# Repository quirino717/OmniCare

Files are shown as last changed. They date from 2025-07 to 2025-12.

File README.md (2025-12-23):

# OmniCare — Robô Móvel Omnidirecional para Navegação Multi-Andares

> Repositório do Trabalho de Conclusão de Curso de Engenharia de Robôs - OmniCare




<p align="center">
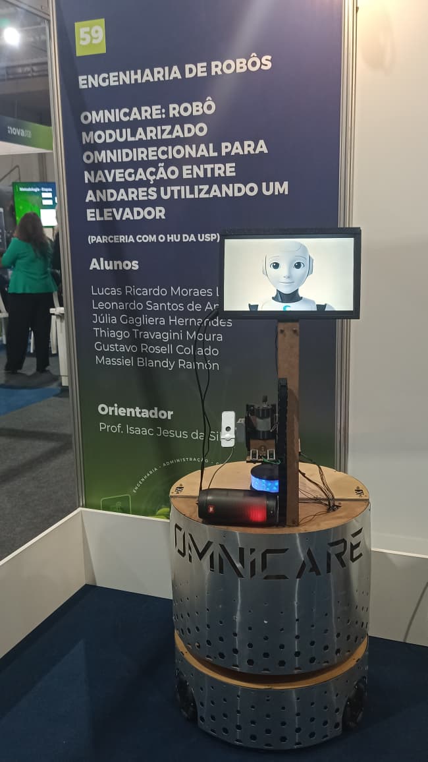
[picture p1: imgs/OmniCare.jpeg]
OmniCare
  
</p>

---

## 📚 Sumário
- [Visão Geral](#visão-geral)
- [Estrutura do Projeto](#instalação-e-build)
- [Como executar o robô de forma teleoperada](#como-executar-o-robô-de-forma-teleoperada)
- [Como executar o robô para mapear (SLAM ToolBox)](#como-executar-o-robô-para-mapear)
- [Como executar a stack do NAV2](#como-executar-a-stack-do-nav2)

- [Documentações](#documentações)
- [Autores](#👤-autores)
- [Licença](#📝-licença)

---
## Visão Geral

O **OmniCare** é um robô móvel omnidirecional desenvolvido para navegação autônoma em ambientes complexos, com capacidade de deslocamento entre **múltiplos andares** utilizando **elevadores reais**.  
O projeto envolve integração profunda de **ROS 2**, **STM32**, **percepção computacional**, **planejamento de movimento**, **manipulação**, além de uma arquitetura de software robusta baseada em máquina de estados.

## Estrutura do Projeto
 
```bash
.
├── firmware/ # Se concentra todos os firmwares utilizados 
├── hardware/ # Documentação e arquivos da parte eletrônica
├── mechanics/ # Arquivos CAD e modelagem mecânica
├── scripts/
│   ├── record_navigation.sh # Script para gravar a bag de navegação
│   ├── record_vision.sh # Script para gravar a bag de visão
│   ├── scripts.sh # Script para setup do robô
│   ├── setup.sh # Script para setup do robô
│   ├── startup.sh # Script que é rodado quando a jetson "boota"
│   └── sync_omnicare.sh # Script para rsync nootebook --> jetson
│
├── software/src/ # ROS 2 workspace
│   ├── omnicare_bringup/ # Launch principal do OmniCare
│   ├── omnicare_control/ # Controle de movimento do robô
│   ├── omnicare_description/ # Descrição do robô (URDF/XACRO)
│   ├── omnicare_msgs/ # Definição de mensagens customizadas
│   ├── omnicare_navigation/ # Configuração do SLAM e NAV2
│   ├── omnicare_simulation/ # Simulação no Gazebo
│   └── omnicare_vision/ # Módulo de visão computacional
│
└── README.md # Este documento
```

## Instalação e Build

```bash
git clone https://github.com/Thgm01/OmniCare.git
cd OmniCare/software/
rosdep install --from-paths . -y --ignore-src
colcon build --symlink-install
source install/setup.bash
```

## Como executar o robô de forma teleoperada
A teleoperação do OmniCare pode ser feita **diretamente na Jetson** (via SSH) ou **remotamente do seu computador**, desde que ambos utilizem o mesmo **ROS_DOMAIN_ID**.

### **1 - Acesse a Jetson via SSH**
```bash
ssh robot@robot.local
```

### **2 - Inicie o robô (bringup completo)**  
Este comando inicializa os drivers, sensores, TFs e toda a estrutura necessária para operar o robô no mundo real.

```bash
ros2 launch omnicare_bringup load_real_robot.launch.py
```

### **3 - Teleoperação usando teclado**

Você pode rodar o teleop **localmente no seu PC** ou **dentro da Jetson via SSH**.

1. Configure no seu PC o mesmo `ROS_DOMAIN_ID` usado pela Jetson:
```bash
export ROS_DOMAIN_ID=<mesmo_da_jetson>
```

2. Execute o teleop do seu computador:
```bash
ros2 run teleop_twist_keyboard teleop_twist_keyboard
```

## Como executar o robô para mapear
O mapeamento do OmniCare pode ser feita **diretamente na Jetson** (via SSH) ou **remotamente do seu computador**, desde que ambos utilizem o mesmo **ROS_DOMAIN_ID**.

### **1 - Acesse a Jetson via SSH**
```bash
ssh robot@robot.local
```

### **2 - Inicie o robô (bringup completo)**  
Este comando inicializa os drivers, sensores, TFs e toda a estrutura necessária para operar o robô no mundo real.

```bash
ros2 launch omnicare_bringup load_real_robot.launch.py
```

### **3 - Teleoperação usando teclado**

Você pode rodar o teleop **localmente no seu PC** ou **dentro da Jetson via SSH**.

1. Configure no seu PC o mesmo `ROS_DOMAIN_ID` usado pela Jetson:
```bash
export ROS_DOMAIN_ID=<mesmo_da_jetson>
```

2. Execute o teleop do seu computador:
```bash
ros2 run teleop_twist_keyboard teleop_twist_keyboard
```

### **4 - Mapeamento usando o SLAM ToolBox**

Você pode rodar **localmente no seu PC** ou **dentro da Jetson via SSH**.

1. Configure no seu PC o mesmo `ROS_DOMAIN_ID` usado pela Jetson:
```bash
export ROS_DOMAIN_ID=<mesmo_da_jetson>
```

2. Execute o teleop do seu computador:
```bash
ros2 launch navigation_pkg mapping_slam_toolbox.launch.py
```

3. Após rodar o launch do SLAM ToolBox, abra o RViz2 no seu computador com essa configuração
```bash
software/src/omnicare_navigation/navigation_pkg/config/rviz/mapping_cartographer.rviz
```

## Como executar a stack do NAV2
A navegação do OmniCare é preferivel ser feita **em um notebook externo** por conta do processamento, é necessário que ambos utilizem o mesmo **ROS_DOMAIN_ID**.

### **1 - Acesse a Jetson via SSH**
```bash
ssh robot@robot.local
```

### **2 - Inicie o robô (bringup completo)**  
Este comando inicializa os drivers, sensores, TFs e toda a estrutura necessária para operar o robô no mundo real.

```bash
ros2 launch omnicare_bringup load_real_robot.launch.py
```

### **3 - Navegando usando a stack do NAV2**

É recomendado rodar **localmente no seu PC** por conta do processamento pesado de CPU.

1. Configure no seu PC o mesmo `ROS_DOMAIN_ID` usado pela Jetson:
```bash
export ROS_DOMAIN_ID=<mesmo_da_jetson>
```

2. Execute o teleop do seu computador:
```bash
ros2 launch navigation_pkg navigation2.launch.py
```

3. Após rodar o launch do NAV2, abra o RViz2 no seu computador com essa configuração
```bash
software/src/omnicare_navigation/navigation_pkg/config/rviz/navigation.rviz
``` 
## Documentações

A documentação do OmniCare está organizada de forma modular, abrangendo mecânica, hardware, firmware e software.  
Cada módulo possui sua própria pasta dedicada, permitindo uma navegação clara e objetiva.

---

### Documentação Mecânica
A pasta [`mechanics/`](mechanics/) contém:

- Modelos CAD completos do robô  
- Estrutura da base omnidirecional  
- Projeto do manipulador linear  
- Especificações de motores, rodas e sensores mecânicos  

---

### Documentação Hardware
A pasta [`hardware/`](hardware/) contém:

- Esquemáticos elétricos  
- Layout da arquitetura eletrônica  
- Detalhamento dos módulos embarcados  

---

### Documentação Software (ROS 2)

O software do OmniCare é composto por múltiplos pacotes ROS 2, cada um contendo suas características e funcionalidades.

### Pacotes ROS 2
---

### 🔹 [omnicare_behavior](software/src/omnicare_behavior/)
O pacote **omnicare_behavior**, a máquina de estados responsável por coordenar toda a missão do robô. É ele quem controla o fluxo completo da navegação entre diferentes andares, integrando percepção, navegação, manipulação e troca de mapas. O Behavior Manager decide quando iniciar a navegação, alinhar ao elevador, interagir com o painel, trocar de mapa no momento correto e retomar o trajeto até o destino final.

---

### 🔹 [omnicare_bringup](software/src/omnicare_bringup/)
O pacote **omnicare_bringup** é responsável por inicializar todo o sistema do robô, tanto no ambiente real quanto no simulador. Ele carrega automaticamente os módulos essenciais, incluindo o ROS 2 Control, a comunicação com os microcontroladores (STM32), e os sensores embarcados, como o LiDAR. Em resumo, é o pacote que prepara todo o ecossistema do OmniCare para operação, garantindo que hardware, drivers e interfaces estejam corretamente configurados antes da execução dos módulos de navegação e comportamento.

---

### 🔹 [omnicare_control](software/src/omnicare_control/)
O **omnicare_control** é um conjunto de três pacotes que implementa toda a camada de controle de baixo nível do OmniCare. Ele integra a cinemática, a dinâmica e as interfaces de hardware do robô, permitindo que o sistema execute movimentos omnidirecionais de forma precisa e compatível com o ROS 2 Control e o movimento do manipulador.

---

### 🔹 [omnicare_description](software/src/omnicare_description/)

O **omnicare_description** é o pacote responsável por reunir toda a descrição física do OmniCare, incluindo o seu URDF completo, as malhas utilizadas para visualização e os plugins necessários para simulação e controle. Ele define a estrutura mecânica, sensores, atuadores e juntas do robô, garantindo que sua representação virtual seja fiel ao modelo real. Além disso, integra os plugins do Gazebo para simulação física e dos ROS 2 Control para conexão com controladores e interfaces de hardware, servindo como a base unificada para visualização, simulação e operação do robô tanto no ambiente virtual quanto no mundo real.

---

### 🔹 [omnicare_hri](software/src/omnicare_hri/)

O **omnicare_hri** engloba os pacotes dedicados à Interação Humano–Robô (HRI) no OmniCare. Ele é composto por um módulo responsável pelas animações faciais do robô — incluindo expressões exibidas na tela frontal, LEDs de sinalização e o buzzer — permitindo que o robô comunique estados e ações de forma mais amigável ao usuário. Complementando essa funcionalidade, o segundo pacote implementa uma interface para um controle remoto baseado em ESP32, possibilitando acionar comandos do robô de maneira simples.

---

### 🔹 [omnicare_msgs](software/src/omnicare_msgs/)

O **omnicare_msgs** é o pacote responsável por definir todas as mensagens customizadas utilizadas pelos diferentes módulos do OmniCare, incluindo topics, services e actions. Ele centraliza estruturas de dados específicas do projeto — como comandos de movimento, estados do comportamento, mensagens do manipulador, sinais de expressão e eventos da navegação multi-andares — garantindo comunicação padronizada e consistente entre os diversos nós do sistema.

---

### 🔹 [omnicare_navigation](software/src/omnicare_navigation/)
O **omnicare_navigation** reúne um conjunto de pacotes responsáveis por toda a camada de navegação do OmniCare. Ele inclui o pacote do LiDAR, que fornece os dados primários de percepção espacial, e o pacote da IMU, atualmente integrado ao sistema mas ainda não utilizado diretamente na navegação. O núcleo deste módulo é o navigation_pkg, que contém os launch files do NAV2, incluindo configuração de planejadores, BTs e parâmetros de navegação. Além disso, o conjunto oferece launchs específicos para mapeamento do ambiente, permitindo a criação e atualização de mapas utilizados pelo Nav2 e pelo AMCL.

---

### 🔹 [omnicare_simulation](software/src/omnicare_simulation/)
O **omnicare_simulation** reúne todos os recursos necessários para a simulação completa do OmniCare no Gazebo, incluindo launch files dedicados para iniciar o robô, seus sensores e o ambiente virtual. Além disso, o pacote implementa serviços auxiliares de teletransporte dentro do simulador para validação da navegação de multi-andares.

---

### 🔹 [omnicare_vision](software/src/omnicare_vision/)
O **omnicare_vision** concentra todos os pacotes relacionados ao sistema de visão do OmniCare. Ele inclui o usb_cam, que atua como driver da câmera e fornece o fluxo de imagens bruto; o floor_detector, responsável por realizar a inferência sobre o display do elevador e classificar corretamente o andar atual; e o dataset_generator, um pacote auxiliar utilizado para gerar datasets automaticamente a partir de rosbags.

## 👤 Autores

**Lucas Lagoeiro**  
Graduando em Engenharia de Robôs – Centro Universitário FEI  
Área: Programação e Elétrica   
[LinkedIn](https://www.linkedin.com/in/llagoeiro/) • [GitHub](https://github.com/LucasLagoeiro)

**Thiago Moura**  
Graduando em Engenharia de Automação e Controle – Centro Universitário FEI  
Área: Programação e Elétrica  
[LinkedIn](https://www.linkedin.com/in/thiago-t-moura/) • [GitHub](https://github.com/Thgm01)

**Massiel Blandy**  
Graduando em Engenharia de Automação e Controle – Centro Universitário FEI  
Área: Programação  
[LinkedIn](https://www.linkedin.com/in/massiel-blandy-ram%C3%B3n-65214829a/) • [GitHub](https://github.com/massiblandy)

**Júlia Hernandes**  
Graduanda em Engenharia Elétrica – Centro Universitário FEI  
Área: Elétrica  
[LinkedIn](https://www.linkedin.com/in/j%C3%BAlia-gagliera-hernandes-40545b221/) 

**Gustavo Rosell**  
Graduando em Engenharia de Automação e Controle – Centro Universitário FEI  
Área: Mecânica  
[LinkedIn](https://linkedin.com/in/gustavo-rosell) 

**Leonardo Quirino**  
Graduando em Engenharia de Robôs – Centro Universitário FEI  
Área: Mecânica  
[LinkedIn](https://www.linkedin.com/in/leonardo-quirino-353486218/)

## 📝 Licença

Este projeto está licenciado sob a Licença MIT.

Isso significa que você pode usar, copiar, modificar, mesclar, publicar, distribuir, sublicenciar e/ou vender cópias do software, desde que mantenha o aviso de copyright e a permissão de licença incluídos em todas as cópias ou partes substanciais do software.

Para mais detalhes, consulte o arquivo [LICENSE](LICENSE).

## 📝 TODO — Documentação dos Pacotes

A seguir está o checklist de pacotes do OmniCare que terão documentação detalhada seguindo o mesmo padrão adotado no `omnicare_behavior`.

### 📦 Pacotes ROS 2

- [x] **omnicare_behavior** — Behavior Manager (FSM, Action Server, multi-andares)
- [x] **omnicare_bringup** — Inicialização do robô (real e simulação)
- [ ] **omnicare_control**
  - [x] omnidrive_stm32
  - [ ] serial_interface_pkg
- [ ] **omnicare_description** — URDF, meshes e plugins
- [ ] **omnicare_hri**
  - [ ] omnicare_expression
- [ ] **omnicare_msgs** — Mensagens, serviços e actions customizadas
- [ ] **omnicare_navigation** — Nav2, LiDAR, IMU e mapeamento
  - [ ] navigation_pkg
- [ ] **omnicare_simulation** — Gazebo, launches e serviços de teleporte
- [ ] **omnicare_vision**
  - [ ] floor_detector
  - [ ] dataset_generator

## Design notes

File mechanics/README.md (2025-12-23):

# OmniCare Mechanics

O OmniCare foi projetado para operar em ambientes hospitalares, com ênfase em mobilidade omnidirecional, modularidade estrutural e compatibilidade com normas de circulação. 
A base possui arquitetura circular, construída com chapas de MDF e perfis de alumínio, permitindo a integração do sistema elétrico, do manipulador e de um compartimento de carga modular. 
O manipulador foi desenvolvido para interação com elevadores, contando com graus de liberdade translacionais e rotacional no efetuador final.

Nesta seção você encontrará todos os materiais relacionados ao desenvolvimento mecânico do robô, incluindo:

- Modelos CAD completos do robô;
- Estrutura da base omnidirecional;
- Projeto do manipulador;
- Especificações de motores e rodas.

Esses arquivos permitem entender a composição estrutural do robô, seus componentes principais e a lógica de montagem mecânica.
O acesso às modelagens e documentos está disponível no link abaixo:

Link para o Drive com os modelos CAD e arquivos mecânicos:
https://drive.google.com/drive/folders/1Ufkg-2wcXs-KffQ5NBY0fZA2kzGGDrn_?usp=drive_link

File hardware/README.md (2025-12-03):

# OmniCare Hardware

O hardware da OmniCare foi projetado para ser **modular, confiável e duradouro**.  
Neste diretório estão reunidos todos os arquivos relacionados ao desenvolvimento elétrico do projeto.  
A seguir, é apresentada a arquitetura geral que descreve como a parte elétrica foi concebida.

## Considerações

Todo o projeto elétrico foi desenvolvido utilizando o software **Altium Designer**, versão *24.8.2*  
(até o momento, ainda é possível utilizar o e-mail institucional da FEI para acesso).

Com exceção da *Driver Board*, todas as placas foram manufaturadas no **CLE da FEI**.  
As placas de duas faces foram projetadas para que os componentes sejam soldados apenas na face **Bottom**,  
utilizando *vias* para permitir a passagem de sinais entre as camadas. Essas vias foram planejadas de forma a permitir o uso de qualquer condutor simples (por exemplo: terminais de resistores ou fios finos).

Dentro de cada pasta estão incluídos:  
– **Arquivos de fabricação**, identificando o local de produção (CLE ou JLCPCB);  
– **PDF de documentação**;  
– **Arquivos do Altium** correspondentes ao projeto.

## Arquitetura Geral

## Placas Eletrônicas da OmniCare

### Power Board
Placa responsável por **receber a energia da bateria**, realizar a **regulação das tensões** utilizadas no robô e fazer a **distribuição segura** para todos os módulos.

### Driver Board
Placa destinada ao **acionamento dos motores**, contendo os circuitos de potência e controle necessários para operar as rodas omnidirecionais com precisão e confiabilidade.

### Base Board
Placa responsável por **interligar os módulos eletrônicos da base**, roteando sinais dos motores, encoders e sensores, além de fornecer **pontos de conexão e organização elétrica** entre os subsistemas.

### IHR Board (HRI Board)
Placa responsável pela **interação humano–robô**, integrando LEDs, botões e elementos visuais utilizados para comunicação e feedback ao usuário.

### Manip Board
Placa dedicada ao **controle do manipulador frontal**, gerenciando motores e sensores usados para acionar os botões do elevador de forma precisa.

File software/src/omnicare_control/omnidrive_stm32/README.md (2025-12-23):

# OmniDrive STM32 (`omnidrive_stm32`)

O **`omnidrive_stm32`** é o pacote responsável por implementar a **Hardware Interface** do **ROS 2 Control** para a base móvel do OmniCare, realizando a ponte entre os controladores de alto nível e o **microcontrolador STM32** que executa o controle de baixo nível dos motores.

Em outras palavras, este pacote “fecha” o conceito do `ros2_control`: enquanto os controladores (ex.: `omnidirectional_controllers`) calculam as velocidades desejadas, o `omnidrive_stm32` é o componente que **envia esses comandos ao STM32** e **lê o feedback** (encoders/estado) para disponibilizar ao restante do sistema.

---

## Considerações

O pacote foi desenvolvido para garantir:

- Integração nativa com o **`omnidirecional_controllers`** do ROS 2 Control;
- Comunicação robusta com o STM32 (ex.: serial/UART/USB, conforme configuração do projeto);
- Publicação de estados para depuração e monitoração;
- Separação clara entre **controle de alto nível (ROS 2)** e **controle de baixo nível (STM32)**.

---

## Diagrama de Fluxo

<p align="center">
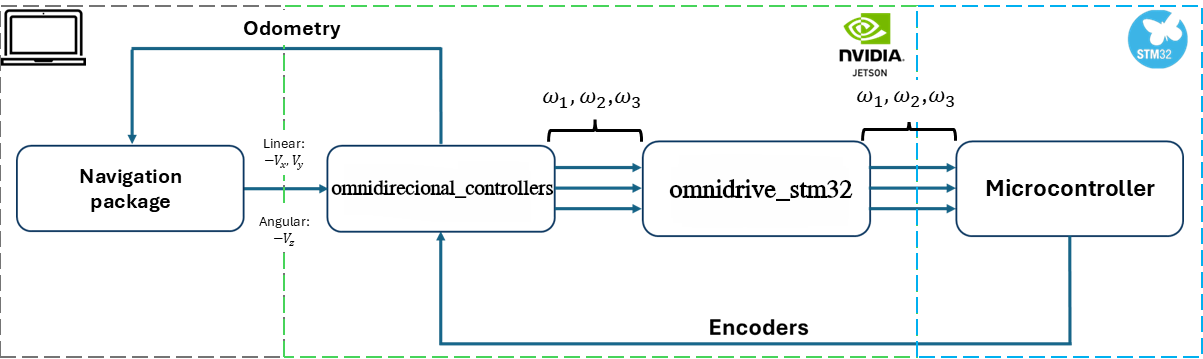
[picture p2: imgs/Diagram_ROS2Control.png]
FSM
  
</p>

---

## Arquitetura Geral

O `omnidrive_stm32` atua como a camada de interface entre:

- **ROS 2 Control** (controladores e controller_manager)
- **STM32** (firmware da base responsável por PWM, leitura de encoders, PID e proteções)

Fluxo simplificado:

1. O ROS 2 Control recebe um comando de velocidade (ex.: `/cmd_vel`);
2. O controlador converte isso em comandos para as rodas;
3. O `omnidrive_stm32` envia esses comandos ao STM32;
4. O STM32 executa o controle de motores e retorna feedback (encoders/estado);
5. O `omnidrive_stm32` publica os estados para o ROS 2 Control (ex.: `joint_states` / estados internos).

---

## Funcionalidades Principais

- **Envio de comandos** de velocidade/rotação para o STM32;
- **Leitura de feedback** dos encoders (e/ou estados reportados pelo firmware);
- Atualização do **estado das juntas** (wheel joints) para o pipeline do ROS 2 Control;
- Parametrização de porta/baudrate/protocolo (dependendo da implementação);
- Suporte a inicialização via bringup, permitindo subir o robô com um único launch.

---

## Integração com Outros Pacotes

O `omnidrive_stm32` é utilizado diretamente por:

- **`omnidirectional_controllers`**: controladores que geram comandos para as rodas;
- **`omnicare_bringup`**: inicialização do ROS 2 Control e carregamento da interface é feita pelo launch **load_real_robot.launch.py**;
- **`omnicare_description`**: definição das juntas e transmissão no URDF para o ROS 2 Control;
- **Firmware STM32** (em `firmware/`): implementação do lado embarcado que espera receber a velocidade desejada para o controle dos motores e envia o feedback dos encoders.

---

## Papel no Sistema

O `omnidrive_stm32` é o pacote que permite que o OmniCare utilize o **ROS 2 Control de ponta a ponta** no robô real, conectando controladores ROS 2 ao hardware físico da base.  
Sem ele, o sistema não conseguiria aplicar os comandos de movimento no STM32 nem obter feedback confiável de estado das rodas, comprometendo a navegação, odometria e controle do robô.

## Links interessantes relacionados ao ROS 2 Control

1 - Esse canal possui alguns videos relacionados ao ros2 control que possa ajudar, inclusive esse pacote é baseado no dele (por isso que possui umas paradas aleatórias nesse pacote kkkkkkk) > https://youtu.be/J02jEKawE5U

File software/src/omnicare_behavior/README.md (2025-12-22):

# OmniCare Behavior Manager

O **omnicare_behavior** é o pacote responsável pelo **gerenciamento de comportamento de alto nível** do OmniCare.  
Ele implementa a **máquina de estados (FSM)** que coordena toda a missão do robô, especialmente a **navegação entre andares distintos**, integrando navegação, percepção, manipulação e troca de mapas.

Neste diretório estão reunidos todos os nós, configurações e lógicas relacionadas à tomada de decisão do robô durante a execução de uma missão completa.

---

## Considerações

O Behavior Manager foi projetado com foco em **robustez, previsibilidade e rastreabilidade**.  
Todas as transições de estado são explícitas, monitoradas e condicionadas a eventos bem definidos, como:

- Feedbacks de navegação (Nav2);
- Resultados da percepção (ex.: detecção de andar);
- Confirmações de ações do manipulador;
- Timeouts e watchdogs de segurança.

A implementação segue boas práticas de sistemas robóticos, permitindo fácil depuração e extensão do comportamento.

---

## Arquitetura Geral

O Behavior Manager atua como um **orquestrador de alto nível**, recebendo informações dos subsistemas e decidindo qual ação deve ser executada a seguir.

De forma simplificada, ele:
1. Inicia a missão a partir de um ponto conhecido;
2. Comanda a navegação até o elevador;
3. Realiza o alinhamento e a interação com o painel;
4. Monitora a troca de andar;
5. Solicita a troca de mapa no momento correto;
6. Retoma a navegação até o destino final.

---

<p align="center">
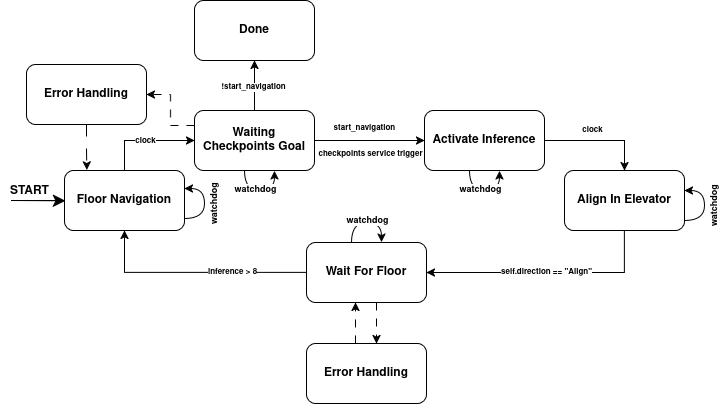
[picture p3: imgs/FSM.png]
FSM
  
</p>

## Máquina de Estados (FSM)

O Behavior Manager é implementado como um **Action Server do ROS 2**, responsável por executar a missão completa de navegação multi-andares.  
A ação recebe quatro parâmetros principais:

- **`world`**: define o ambiente carregado (por exemplo, HU ou FEI);
- **`initial`**: andar inicial, utilizado para determinar o ponto de partida da missão;
- **`target`**: andar alvo que o robô deve alcançar;
- **`simulation`**: flag utilizada para diferenciar execução em simulação ou no robô real.

A partir desses parâmetros, a máquina de estados é iniciada e evolui de forma sequencial, conforme descrito a seguir.

---

### **1. Floor Navigation**

Estado inicial da FSM.  
É responsável por:

- Fazer o parsing do arquivo de configuração ([config/floor_maps_params.yaml](config/floor_maps_params.yaml)) 
- Selecionar e carregar o mapa correspondente ao andar atual;
- Definir a pose inicial do robô naquele mapa;
- Inicializar a sequência de *checkpoints* de navegação definidos para o andar.

Esse estado prepara o sistema para a navegação local antes da interação com o elevador.

---

### **2. Waiting Checkpoints Goal**

Neste estado, o Behavior Manager **monitora a execução dos checkpoints** enviados ao sistema de navegação.  
A transição para o próximo estado ocorre somente quando o último checkpoint do andar atual é atingido, garantindo que o robô chegou corretamente à área do elevador.

---

### **3. Activate Inference**

Estado responsável por **ativar o pipeline de visão computacional** do robô.  
A inferência não permanece ativa durante toda a missão com o objetivo de **reduzir consumo energético** e aumentar a autonomia das baterias do OmniCare.  
A partir deste ponto, o robô passa a analisar o display do elevador.

---

### **4. Align to Elevator Display**

Com a inferência ativa, o robô entra no estado de **alinhamento fino com o display do elevador**.  
Esse alinhamento tem como objetivo compensar erros acumulados da navegação baseada no Nav2, garantindo que o robô esteja posicionado de forma precisa em relação ao elevador e coerente com a pose inicial esperada no próximo mapa.

---

### **5. Waiting for Target Floor**

Após o alinhamento, o Behavior Manager passa a **monitorar continuamente a inferência do display**, aguardando a identificação do andar alvo especificado no parâmetro `target`.  
Este estado permanece ativo até que o robô detecte a chegada ao andar correto.

---

### **6. Target Floor Confirmation**

Quando a visão classifica o andar alvo **oito vezes consecutivas**, o sistema considera, com alta confiabilidade, que o robô chegou ao andar desejado.  
Essa estratégia reduz falsos positivos e garante robustez na detecção do andar.

Confirmada a chegada, a FSM retorna ao estado **Floor Navigation**, agora:

- Carregando o mapa do andar alvo;
- Definindo a nova pose inicial;
- Iniciando os checkpoints correspondentes ao novo andar.

---

### **7. Mission Completion**

Por fim, quando o estado **Waiting Checkpoints Goal** detecta a conclusão dos checkpoints do andar alvo, a máquina de estados é encerrada e a ação é finalizada com sucesso, indicando que a missão de navegação multi-andares foi concluída.

---

## Como executar o Behavior Manager

O **Behavior Manager** é implementado como um **Action Server do ROS 2**.  
Após iniciar o nó, o robô permanece em espera até que uma **requisição de action** seja enviada. A missão de navegação multi-andares **não é iniciada automaticamente**.

---

### Iniciar o Action Server

Primeiramente, execute o nó do Behavior Manager:

```bash
ros2 run omnicare_behavior behavior_manager
```

Após esse comando, o Action Server estará ativo e pronto para receber requisições.

---

### Chamar a Action

Para iniciar a missão, é necessário enviar uma requisição ao Action Server contendo os parâmetros da navegação:

- `world`: ambiente carregado (ex.: `HU` ou `FEI`)
- `initial`: andar inicial
- `target`: andar alvo
- `simulation`: indica se a execução é em simulação ou no robô real
- `presentation`: Go Horse feito para a apresentação de TCC 2 (manter False, caso queira utilizar perguntar para alguém do software da velha guarda - Lagoeiro)

Exemplo de chamada da action via linha de comando:

```bash
ros2 action send_goal   /omnicare/behavior/run_mission   omnicare_msgs/action/RunMission   '{world: presentation, simulation: False, initial: 5, target: 4, presentation: False}'   --feedback
```

Após o envio da action, o Behavior Manager inicia automaticamente a máquina de estados e passa a executar todas as etapas da missão.

---

### Monitoramento da Execução

Durante a execução, o Action Server fornece **feedback contínuo**, permitindo acompanhar:

- O estado atual da máquina de estados  
- O progresso da navegação  
- Eventos de troca de andar  
- A finalização ou falha da missão  

A action é concluída apenas quando toda a missão de navegação multi-andares termina com sucesso ou quando ocorre alguma condição de erro tratável.

## Arquivo de Configuração: `floor_maps_params.yaml`

O arquivo **`floor_maps_params.yaml`** é responsável por centralizar todas as informações relacionadas aos **andares**, **mapas** e **checkpoints de navegação** utilizados pelo Behavior Manager.  
Ele permite configurar o comportamento multi-andares do robô de forma **parametrizável**, sem a necessidade de modificar o código-fonte.

---

### Estrutura Geral do Arquivo

Cada andar é descrito como uma entrada independente no arquivo YAML, contendo informações como:

- Nome ou identificador do andar;
- Caminho para o mapa correspondente;
- Pose inicial do robô naquele mapa;
- Lista ordenada de *checkpoints* de navegação.

De forma simplificada, cada andar define como o robô deve se comportar ao entrar naquele ambiente.

---

### Definição de um Andar

Para cada andar, são definidos:

- **Mapa**: arquivo `.yaml` do mapa utilizado pelo Nav2;
- **Pose inicial**: posição e orientação inicial do robô ao carregar o mapa;
- **Checkpoints**: sequência de metas que o robô deve percorrer naquele andar.

Esses checkpoints são utilizados pelo Behavior Manager para guiar o robô até regiões específicas, como a entrada do elevador ou o destino final.

---

### Adicionando um Novo Andar

Para adicionar um novo andar ao sistema, basta:

1. Criar o mapa do ambiente (via [SLAM](/software/src/omnicare_navigation/navigation_pkg));
2. Salvar o mapa no diretório correspondente;
3. Adicionar uma nova entrada no arquivo `floor_maps_params.yaml`, informando:
   - O caminho do mapa;
   - A pose inicial do robô;
   - A lista de checkpoints desejados.

Após isso, o novo andar passa a ser automaticamente reconhecido pelo Behavior Manager e pode ser utilizado como **andar inicial ou alvo** na chamada da action.

---

### Arquivo Utilizado nos Vídeos de Demonstração (Real e Simulação)

Os exemplos abaixo correspondem ao **arquivo oficial `floor_maps_params.yaml` utilizado nas gravações dos vídeos de demonstração do OmniCare**, tanto no **robô real** quanto em **simulação**, no ambiente da **FEI**.

---

#### Configuração para Robô Real

```yaml
FEI:
  real:
    '5':
      map_path: "config/maps/FEI/FEI_quintoAndar_elevadorManutencao.yaml"
      checkpoints: "quinto_andar_manutencao"
      position:
        x: 3.78
        y: -0.76
      orientation:
        yaw: 0.83
    '4':
      map_path: "config/maps/FEI/FEI_quartoAndar_elevadorManutencao.yaml"
      checkpoints: "quarto_andar_manutencao"
      position:
        x: -5.04
        y: 12.61
      orientation:
        yaw: -1.21
...
```

Essa configuração define os mapas, poses iniciais e checkpoints utilizados pelo robô físico durante a navegação multi-andares, exatamente como demonstrado nos vídeos gravados no ambiente real da FEI.

---

#### Configuração para Simulação

```yaml
...
  sim:
    '5':
      map_path: "config/maps/simulation/simulation_quintoAndar_firstElevator.yaml"
      checkpoints: "simulation_FEI_quintoAndar"
      position:
        x: -3.986
        y: -1.120
      orientation:
        yaw: 0.95
      teleport:
        position:
          x: 3.78
          y: -0.76
          z: 0.120965
        orientation:
          yaw: 0.83
```

Na simulação, além do mapa, pose inicial e checkpoints, é definido o campo **`teleport`**, utilizado para **reposicionar o robô diretamente no ambiente do Gazebo** após a troca de andar.  
Esse mecanismo permite reproduzir o comportamento do elevador no simulador, mantendo coerência com as poses utilizadas no robô real.

---

Com essa separação entre **real** e **simulação**, o Behavior Manager consegue reutilizar a mesma lógica de navegação e troca de mapas, adaptando automaticamente o comportamento conforme o modo de execução.

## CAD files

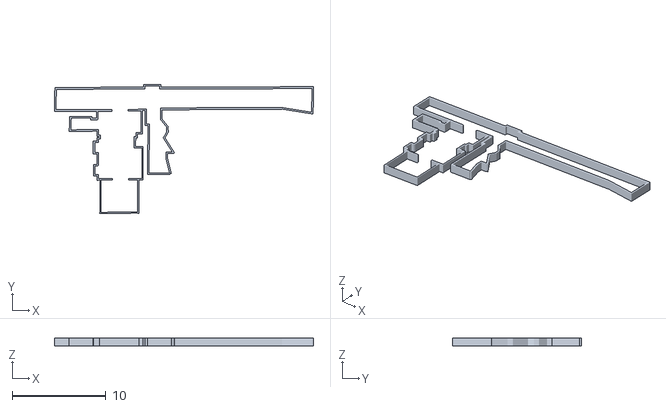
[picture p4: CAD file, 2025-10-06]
software/src/omnicare_simulation/simulation/stl/HU_primeiroAndar.stl
27.6 x 13.7 x 0.879

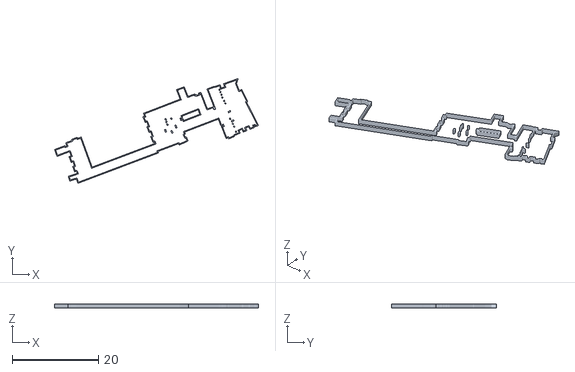
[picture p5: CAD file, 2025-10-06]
software/src/omnicare_simulation/simulation/stl/HU_terceiroAndarHU.stl
47.3 x 24.2 x 0.887

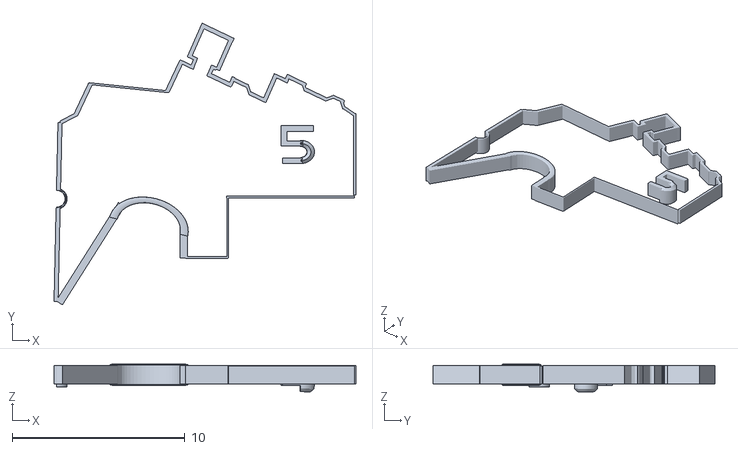
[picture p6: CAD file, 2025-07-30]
software/src/omnicare_simulation/simulation/stl/quintoAndar.stl
17.5 x 16.3 x 1.60

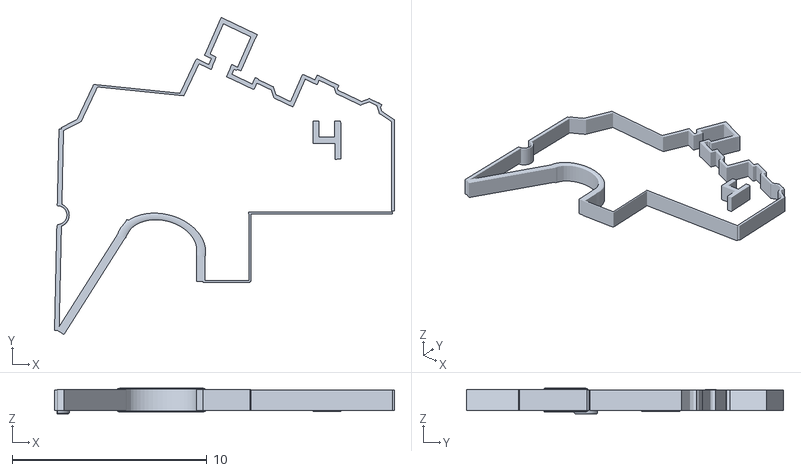
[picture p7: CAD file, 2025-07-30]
software/src/omnicare_simulation/simulation/stl/quartoAndar.stl
17.5 x 16.3 x 1.33

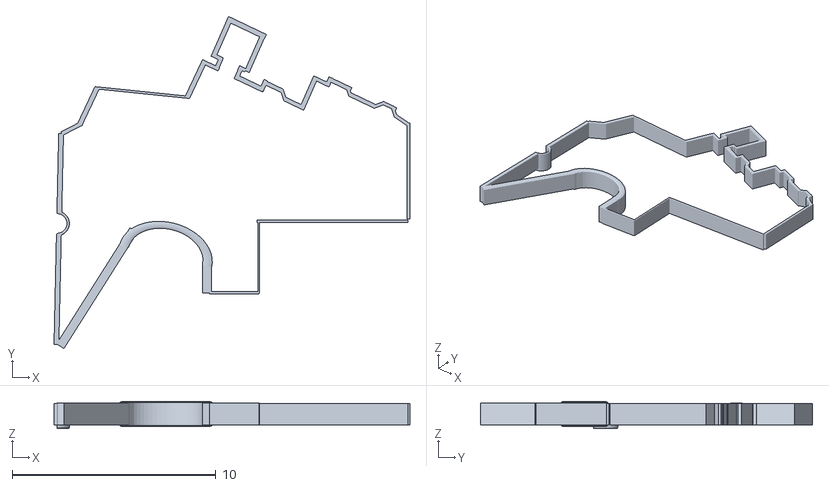
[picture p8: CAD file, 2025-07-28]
software/src/omnicare_simulation/simulation/stl/classicMap.stl
17.5 x 16.3 x 1.33

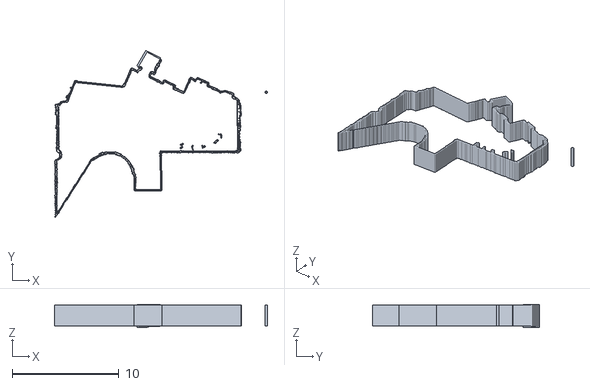
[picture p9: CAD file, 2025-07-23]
software/src/omnicare_simulation/simulation/stl/mapUsingConversion.stl
20.0 x 15.7 x 2.19

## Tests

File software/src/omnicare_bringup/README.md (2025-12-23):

# OmniCare Bringup

O **omnicare_bringup** é o pacote responsável pela **inicialização completa do OmniCare**, tanto no **robô real** quanto no **ambiente de simulação**.  
Ele centraliza todos os *launch files* necessários para subir o sistema de forma consistente, garantindo que sensores, controladores, interfaces de hardware e módulos de software estejam corretamente configurados antes da execução das missões.

Este pacote é o ponto de entrada principal para a operação do robô.

---

## Considerações

O bringup foi projetado para:

- Facilitar a inicialização do sistema com um único comando;
- Garantir consistência entre simulação e robô real;
- Reduzir erros de configuração manual;
- Centralizar parâmetros críticos de inicialização.

Sempre que possível, a lógica de inicialização é mantida no `omnicare_bringup`, evitando que outros pacotes precisem lidar diretamente com dependências de hardware ou configuração global do sistema.

---

## Arquitetura Geral

O pacote atua como um **orquestrador de inicialização**, sendo responsável por subir e interligar os seguintes componentes:

- Descrição do robô (URDF);
- ROS 2 Control e controladores;
- Comunicação com microcontroladores (STM32);
- Sensores embarcados (ex.: LiDAR);
- Interfaces necessárias para navegação e controle.

Ele não implementa lógica de comportamento ou navegação, apenas prepara o ambiente para que esses módulos possam operar corretamente.

---

## Funcionalidades Principais

O `omnicare_bringup` é responsável por:

- Inicializar o **ROS 2 Control**, carregando controladores e interfaces de hardware;
- Estabelecer a comunicação com os **microcontroladores da base**;
- Inicializar sensores essenciais, como o **LiDAR**;
- Carregar a descrição física do robô;

---

## Launch Files

Os principais *launch files* disponíveis neste pacote incluem:

- **`load_real_robot.launch.py`**  
  Responsável por inicializar o OmniCare no robô real, incluindo:
  - ROS 2 Control;
  - Interfaces de hardware;
  - Sensores físicos;
  - Configurações específicas do ambiente real.

- **`load_sim_robot.launch.py`**  
  Responsável por inicializar o OmniCare em **simulação**, incluindo:
    - Carregar o modelo do robô no Gazebo;
    - Publicar corretamente o URDF via `robot_state_publisher`;
    - Inicializar sensores e estimadores em modo simulado;
    - Permitir a escolha dinâmica do ambiente (FEI ou HU);
    - Disponibilizar ferramentas de depuração, como o RViz.

<br>

---

## Como Executar

### Robô Real
```bash
ros2 launch omnicare_bringup load_real_robot.launch.py
```

### Simulação
```bash
ros2 launch omnicare_bringup load_sim_robot.launch.py
```

Após a execução de qualquer um dos modos, o robô estará pronto para receber comandos de teleoperação ou iniciar missões automáticas através do Behavior Manager.

---

## Papel no Sistema

O **omnicare_bringup** é responsável por **preparar todo o ecossistema do OmniCare para operação**.  
Sem ele, os pacotes funcionariam apenas de forma isolada; com ele, o sistema é iniciado de maneira estruturada, confiável e reprodutível, tanto em simulação quanto no robô real.

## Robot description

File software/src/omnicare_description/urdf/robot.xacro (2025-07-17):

<?xml version="1.0"?>
<robot name="robot" xmlns:xacro="http://www.ros.org/wiki/xacro">

    <xacro:arg name="sim_mode" default="false" />

    <xacro:if value="$(arg sim_mode)">
        <xacro:include filename="$(find omnicare_description)/urdf/robot.gazebo" />
    </xacro:if>
    <xacro:unless value="$(arg sim_mode)">
        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
        <link name="lidar_link"></link>
        <joint name="lidar_to_base" type="fixed">
            <parent link="base_link" />
            <child link="lidar_link" />
            <origin rpy="0.0 0 3.14" xyz="0 0 0" />
        </joint>

        <xacro:include filename="$(find omnicare_description)/urdf/ros2_control.xacro" />
    </xacro:unless>

    <xacro:include filename="$(find omnicare_description)/urdf/camera.xacro" />


    <joint name="base_footprint_to_base_link" type="fixed">
        <parent link="base_footprint" />
        <child link="base_link" />
        <origin rpy="0.0 0 0" xyz="0 0 0" />
    </joint>
    <link name="base_footprint"></link>


    <link name="base_link"></link>
    <joint name="base_link_to_base" type="fixed">
        <parent link="base_link" />
        <child link="base" />
        <origin rpy="0.0 0 1.57" xyz="0 0 0" />
    </joint>
    <link name="base">
        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
        <inertial>
            <origin xyz="-2.5725654066226820008e-17 -0.00072713798642877675634 0.1130692369102963557" rpy="0 0 0" />
            <mass value="6.6083023665046667361" />
            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
        </inertial>
    </link>

    <link name="roda">
        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
        <inertial>
            <origin xyz="2.488178870261553677e-17 -5.0324958787843994577e-18 -0.036248827632811911337" rpy="0 0 0" />
            <mass value="0.17417946931200009586" />
            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
        </inertial>
    </link>

    <link name="rolete">
        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
        <inertial>
            <origin xyz="-1.8827844672617356948e-33 8.8261553917125876786e-19 -0.017500000000000064115" rpy="0 0 0" />
            <mass value="0.0095254397280000006887" />
            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
        </inertial>
    </link>

    <joint name="w1_external_1_passive" type="fixed">
        <origin xyz="0.01750000000000022024 -0.050000000000000002776 -0.046999999999999930722" rpy="-3.141592653589793116 -1.570796326794896558 0" />
        <parent link="roda" />
        <child link="rolete" />
        <axis xyz="0 0 1">
            <dynamics damping="1.0" friction="1.0" /> 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
        </axis>
        <limit effort="1" velocity="20" />

    </joint>

    <link name="rolete_2">
        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
        <inertial>
            <origin xyz="2.4286128663675299322e-17 1.5253801182852536392e-20 -0.017500000000000053707" rpy="0 0 0" />
            <mass value="0.0095254397280000006887" />
            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
        </inertial>
    </link>

    <joint name="w1_external_2_passive" type="fixed">
        <origin xyz="0.052051270189221954254 -0.009844555433772231301 -0.047000000000000041744" rpy="1.570796326794896558 4.1633363423452281929e-17 2.6179938779914921909" />
        <parent link="roda" />
        <child link="rolete_2" />
        <axis xyz="0 0 1">
            <dynamics damping="1.0" friction="1.0" /> 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
        </axis>
        <limit effort="1" velocity="20" />

    </joint>

    <link name="rolete_3">
        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
        <inertial>
            <origin xyz="-5.5511151231257827021e-17 1.5253801182858512794e-20 -0.017500000000000067585" rpy="0 0 0" />
            <mass value="0.0095254397280000006887" />
            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
        </inertial>
    </link>

    <joint name="w1_external_3_passive" type="fixed">
        <origin xyz="0.052051270189221968132 0.0098445554337722868121 -0.047000000000000041744" rpy="-1.570796326794896558 4.163336342345265787e-17 -2.6179938779914921909" />
        <parent link="roda" />
        <child link="rolete_3" />
        <axis xyz="0 0 1">
            <dynamics damping="1.0" friction="1.0" /> 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
        </axis>
        <limit effort="1" velocity="20" />

    </joint>

    <link name="rolete_4">
        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
        <inertial>
            <origin xyz="-1.8827844672617356948e-33 1.5253801182855310935e-20 -0.017500000000000064115" rpy="0 0 0" />
            <mass value="0.0095254397280000006887" />
            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
        </inertial>
    </link>

    <joint name="w1_external_4_passive" type="fixed">
        <origin xyz="0.01750000000000022024 0.050000000000000002776 -0.046999999999999930722" rpy="-3.141592653589793116 -1.570796326794896558 0" />
        <parent link="roda" />
        <child link="rolete_4" />
        <axis xyz="0 0 1">
            <dynamics damping="1.0" friction="1.0" /> 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
        </axis>
        <limit effort="1" velocity="20" />

    </joint>

    <link name="rolete_5">
        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
        <inertial>
            <origin xyz="2.7755575615628907348e-17 -5.5495897430074969875e-17 -0.017500000000000053707" rpy="0 0 0" />
            <mass value="0.0095254397280000006887" />
            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
        </inertial>
    </link>

    <joint name="w1_external_5_passive" type="fixed">
        <origin xyz="-0.034551270189221897078 0.040155444566227743719 -0.046999999999999930722" rpy="1.570796326794896558 9.7144514654709209156e-17 2.6179938779914921909" />
        <parent link="roda" />
        <child link="rolete_5" />
        <axis xyz="0 0 1">
            <dynamics damping="1.0" friction="1.0" /> 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
        </axis>
        <limit effort="1" velocity="20" />

    </joint>

    <link name="rolete_6">
        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
        <inertial>
            <origin xyz="-1.0408340855860839485e-17 1.5253801182855816492e-20 -0.017500000000000060646" rpy="0 0 0" />
            <mass value="0.0095254397280000006887" />
            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
        </inertial>
    </link>

    <joint name="w1_external_6_passive" type="fixed">
        <origin xyz="-0.034551270189221897078 -0.040155444566227743719 -0.046999999999999986233" rpy="-1.570796326794896558 4.163336342345242984e-17 -2.6179938779914930791" />
        <parent link="roda" />
        <child link="rolete_6" />
        <axis xyz="0 0 1">
            <dynamics damping="1.0" friction="1.0" /> 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
        </axis>
        <limit effort="1" velocity="20" />

    </joint>

    <link name="rolete_7">
        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
        <inertial>
            <origin xyz="-2.7755575615628907348e-17 6.954147705090087065e-18 -0.017500000000000060646" rpy="0 0 0" />
            <mass value="0.0095254397280000006887" />
            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
        </inertial>
    </link>

    <joint name="w1_internal_1_passive" type="fixed">
        <origin xyz="0.0098445554337722885468 -0.052051270189221947315 -0.02899999999999994249" rpy="0.52359877559829937077 -1.570796326794896558 0" />
        <parent link="roda" />
        <child link="rolete_7" />
        <axis xyz="0 0 1">
            <dynamics damping="1.0" friction="1.0" /> 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
        </axis>
        <limit effort="1" velocity="20" />

    </joint>

    <link name="rolete_8">
        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
        <inertial>
            <origin xyz="-1.3877787807814456755e-17 -2.7740321814446059445e-17 -0.017500000000000043299" rpy="0 0 0" />
            <mass value="0.0095254397280000006887" />
            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
        </inertial>
    </link>

    <joint name="w1_internal_2_passive" type="fixed">
        <origin xyz="0.050000000000000016653 -0.017500000000000019013 -0.028999999999999970246" rpy="-1.570796326794896558 1.035468818874435832e-17 3.141592653589793116" />
        <parent link="roda" />
        <child link="rolete_8" />
        <axis xyz="0 0 1">
            <dynamics damping="1.0" friction="1.0" /> 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
        </axis>
        <limit effort="1" velocity="20" />

    </joint>

    <link name="rolete_9">
        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
        <inertial>
            <origin xyz="6.826351802735963352e-34 1.5253801182852948662e-20 -0.017500000000000071054" rpy="0 0 0" />
            <mass value="0.0095254397280000006887" />
            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
        </inertial>
    </link>
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

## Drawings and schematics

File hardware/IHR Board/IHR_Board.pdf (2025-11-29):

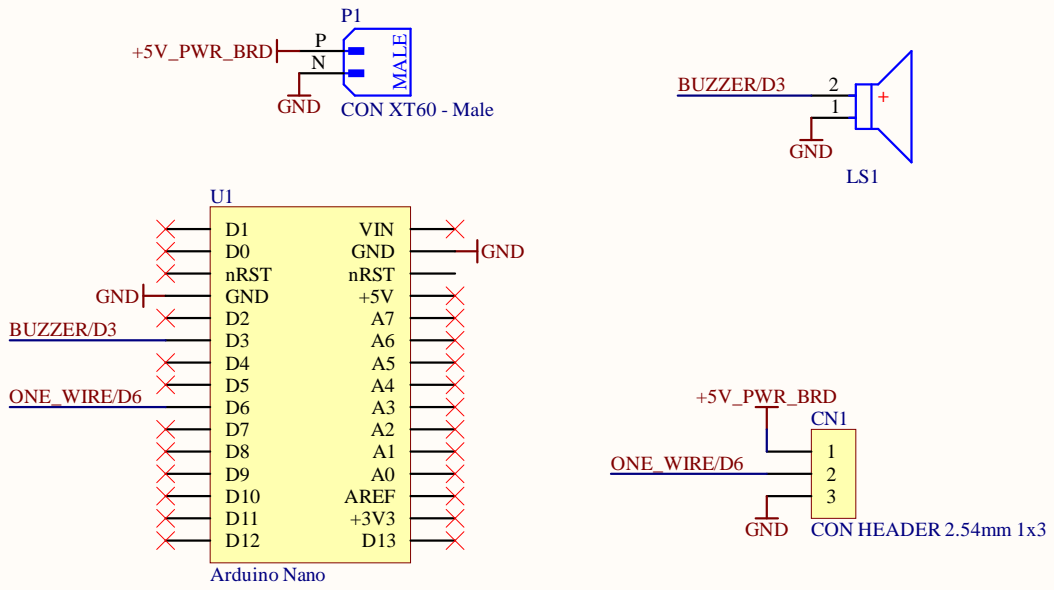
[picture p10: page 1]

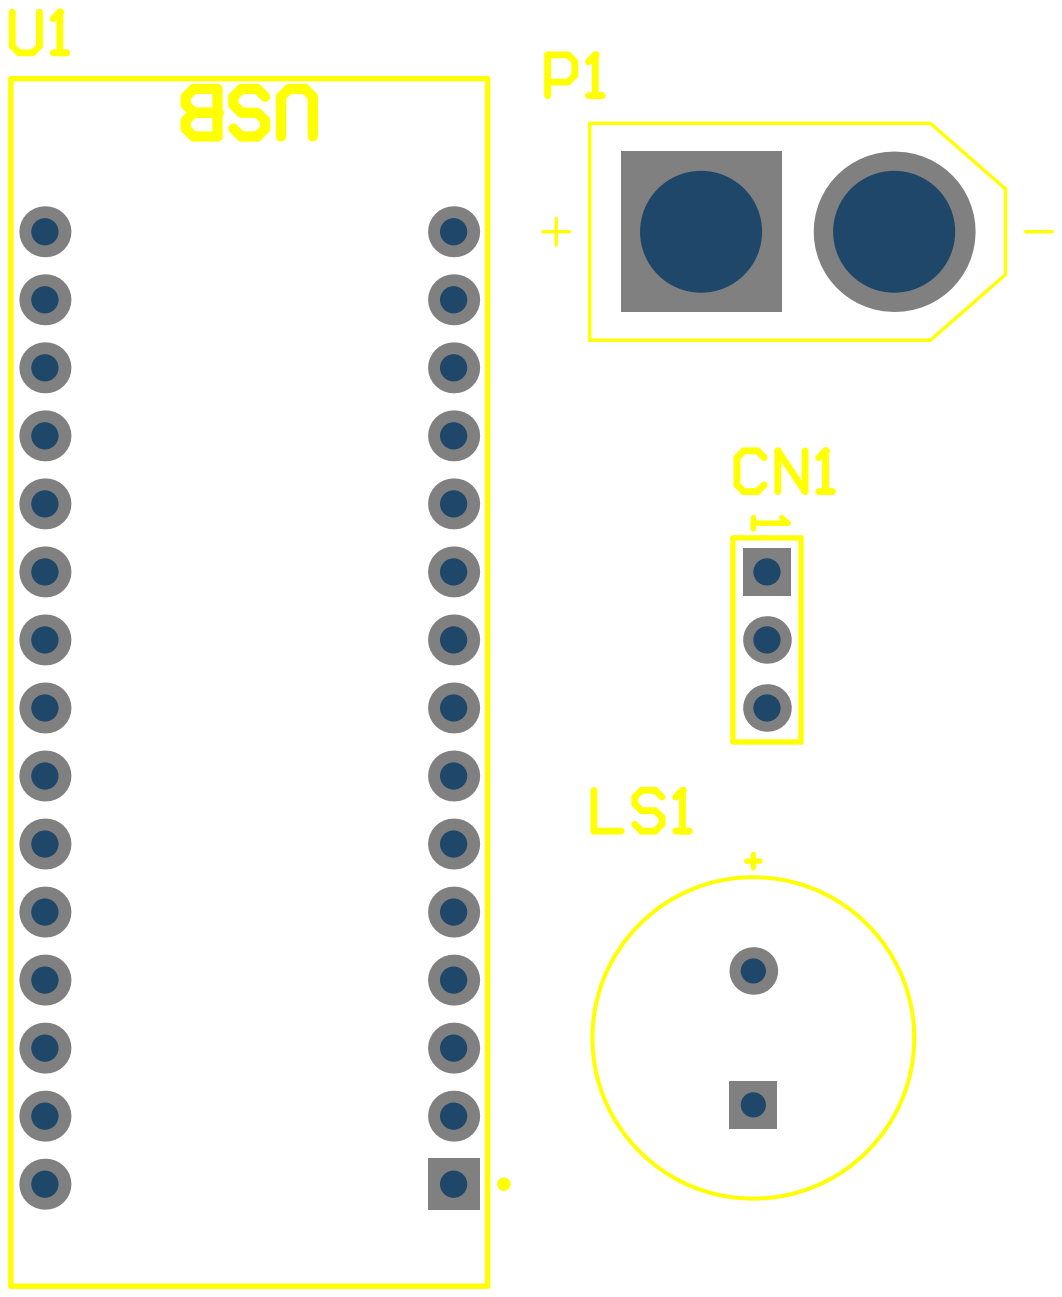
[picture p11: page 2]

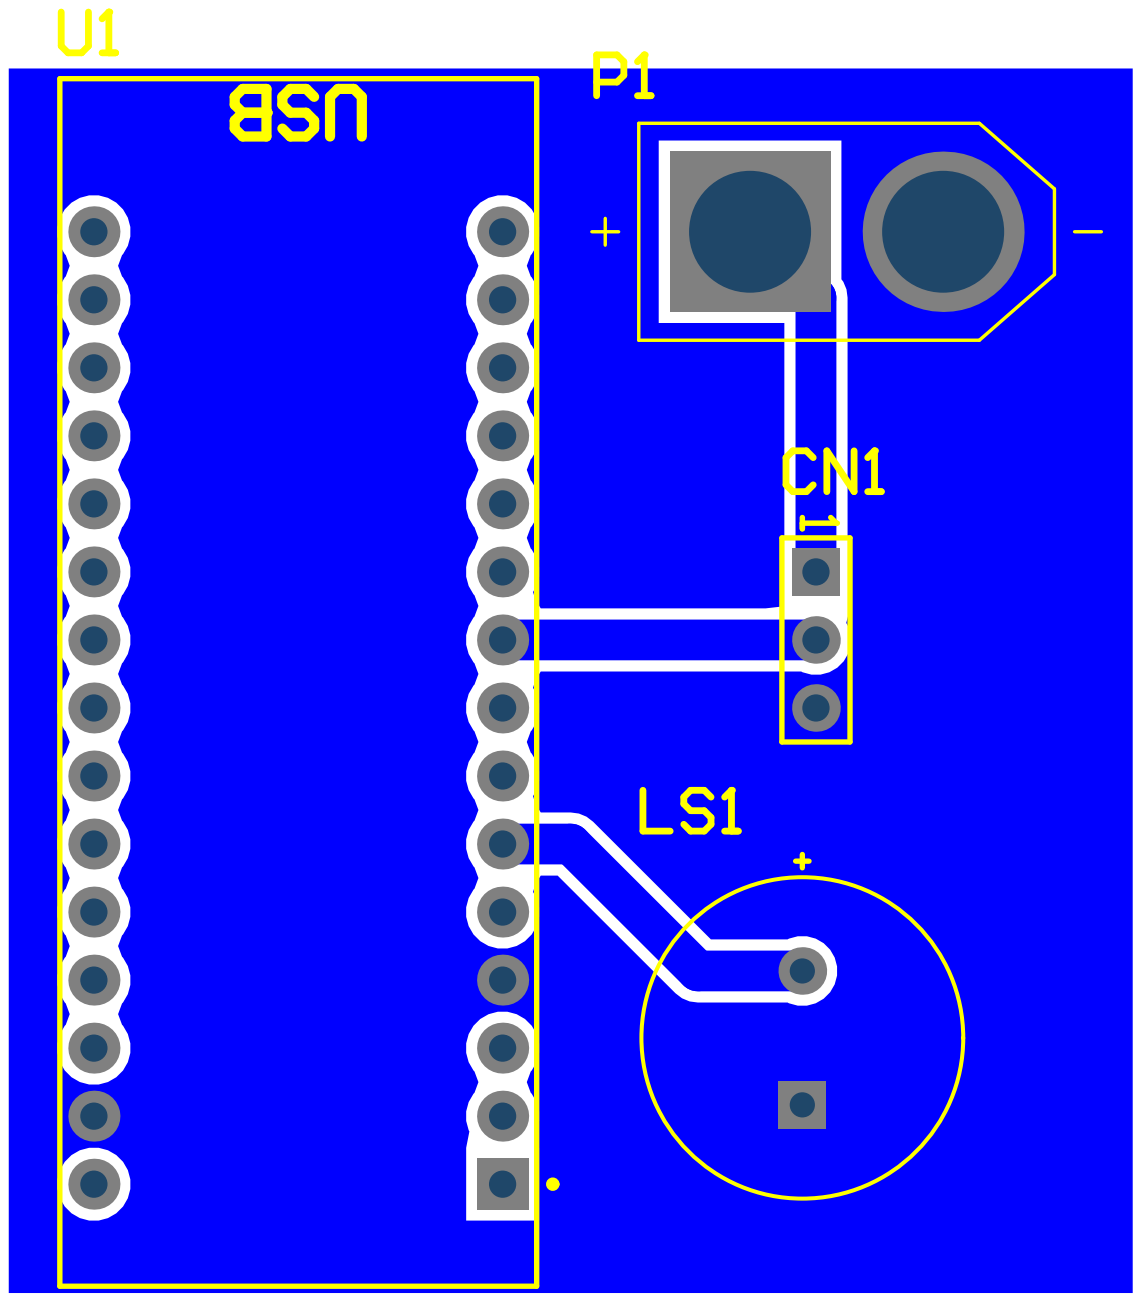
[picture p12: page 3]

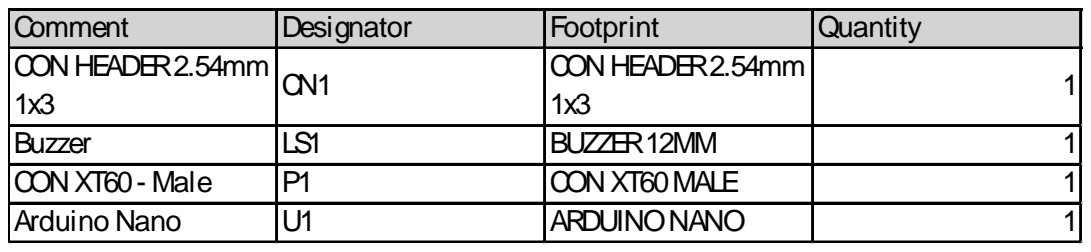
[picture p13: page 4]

Comment | Designator | Footprint | Quantity
CON HEADER2.54mm 1x3 | CN1 | CON HEADER2.54mm 1x3 | 1

Buzzer | LS1 | BUZZER12MM | 1
CON XT60- Male | P1 | CON XT60MALE | 1
Arduino Nano | U1 | ARDUINONANO | 1

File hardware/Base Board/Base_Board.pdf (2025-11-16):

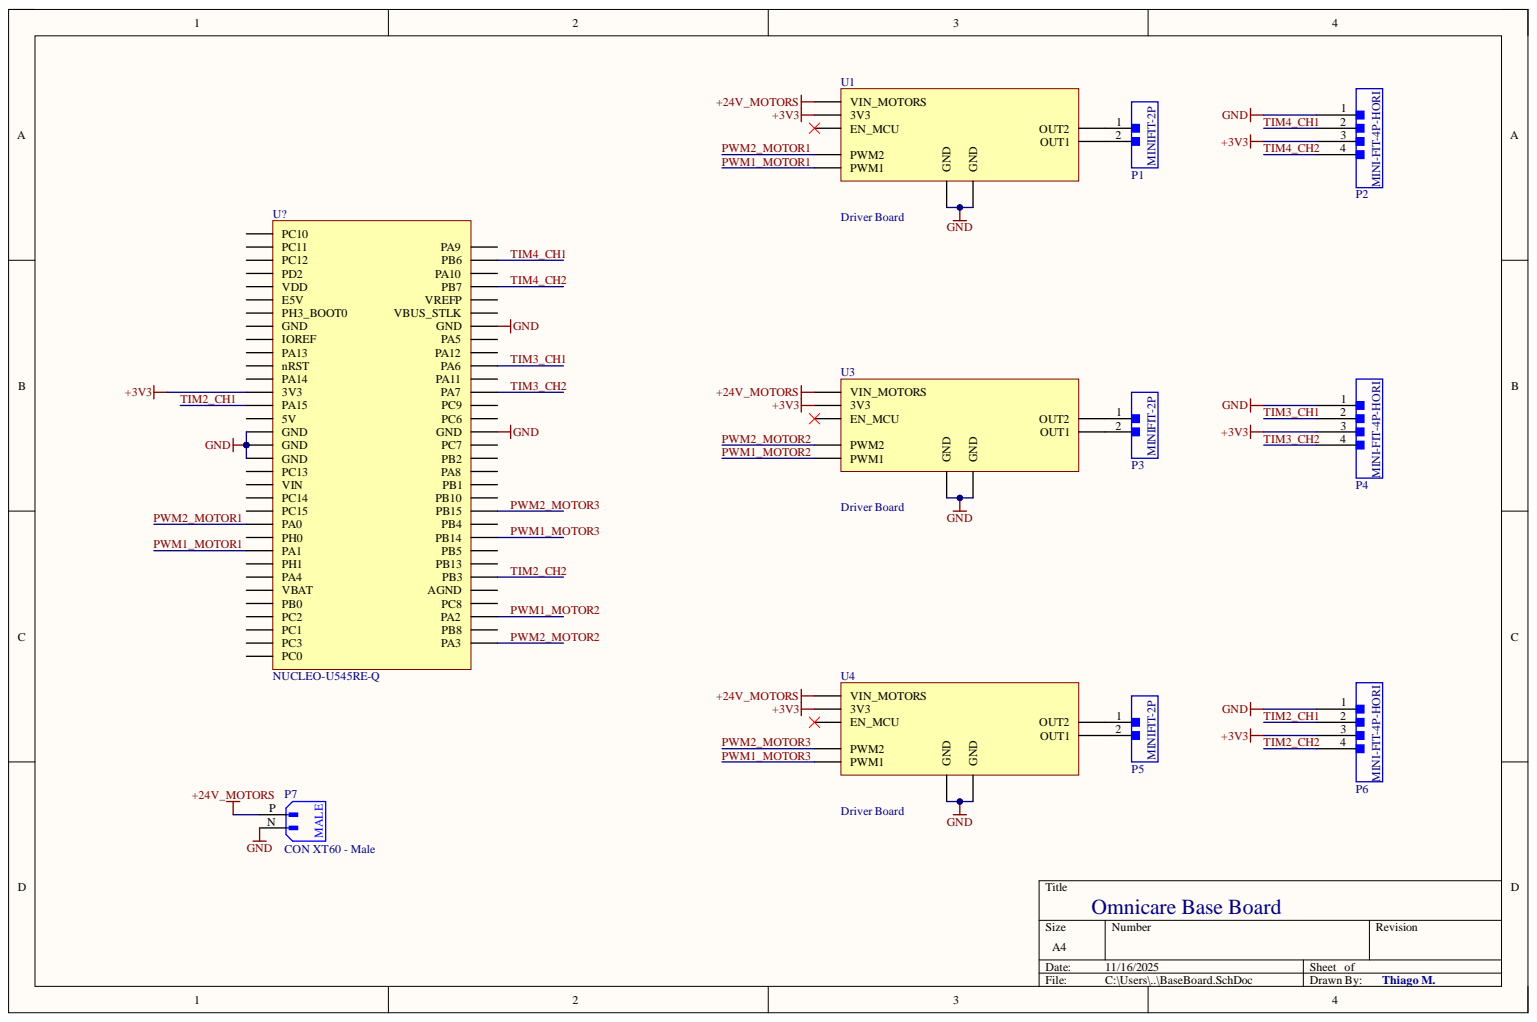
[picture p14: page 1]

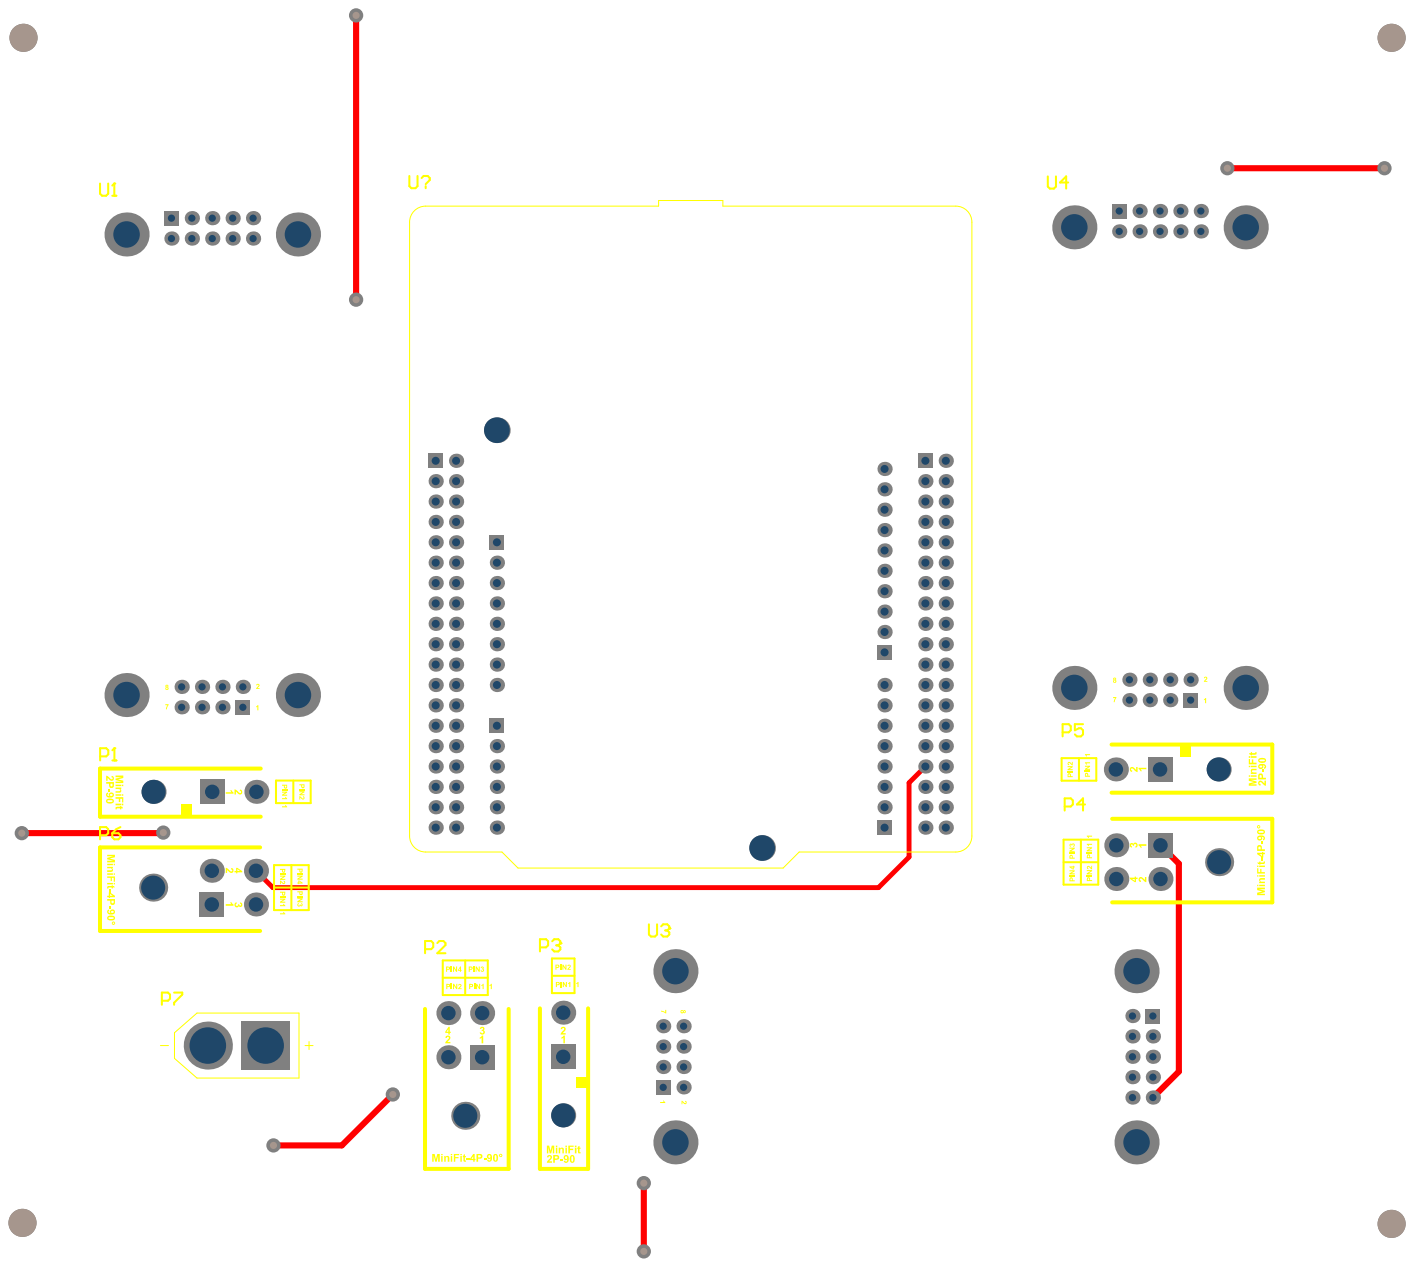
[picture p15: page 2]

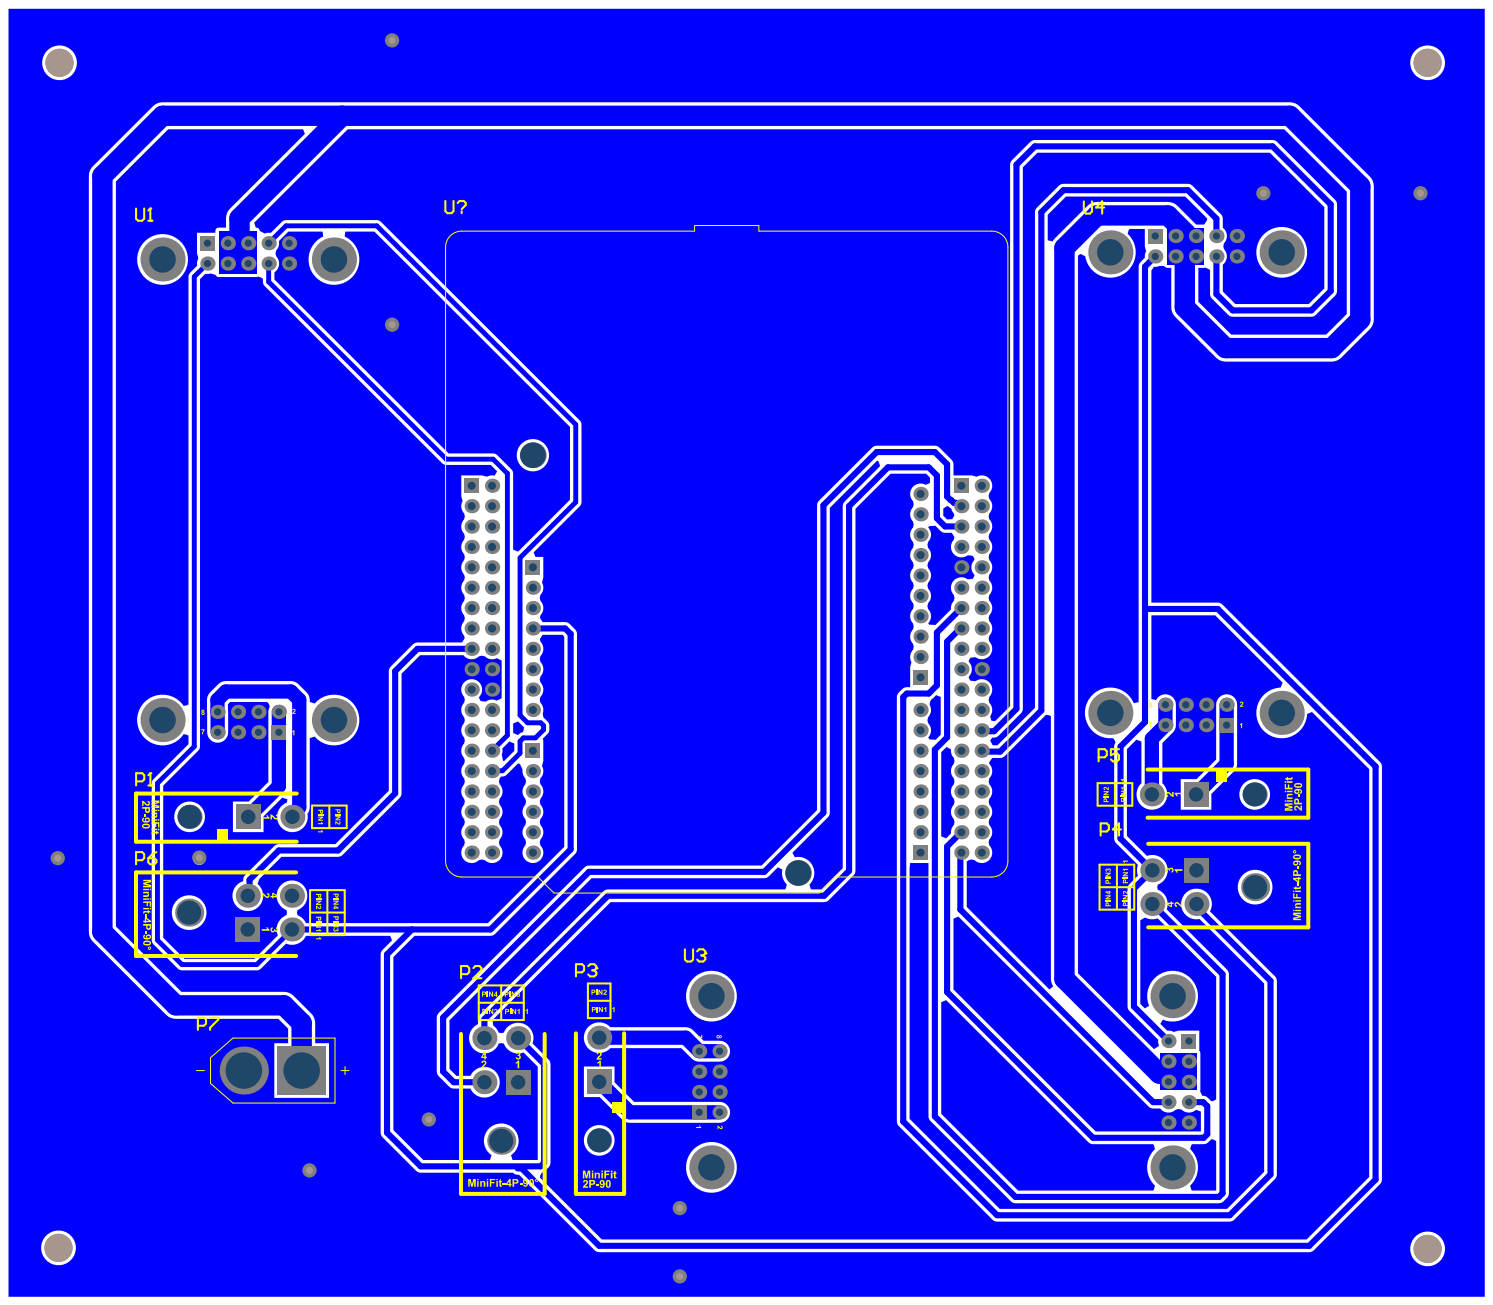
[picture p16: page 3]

Comment | Designator | Footprint | Quantity
CON MINI FIT2P- 1x2 | P1, P3, P5 | CON MINI FIT2POS-1x2- 90DG | 3
CON MINI FIT4P- 2x2-HORIZONTAL | P2, P4, P6 | CON MINI FIT4POS-2x2- 90DG | 3
CON XT60- Male | P7 | CON XT60MALE | 1
Driver Board | U1, U3, U4 | Driver Board | 3
NUCLEO-U545RE-Q | U? | NUCLEO64 | 1

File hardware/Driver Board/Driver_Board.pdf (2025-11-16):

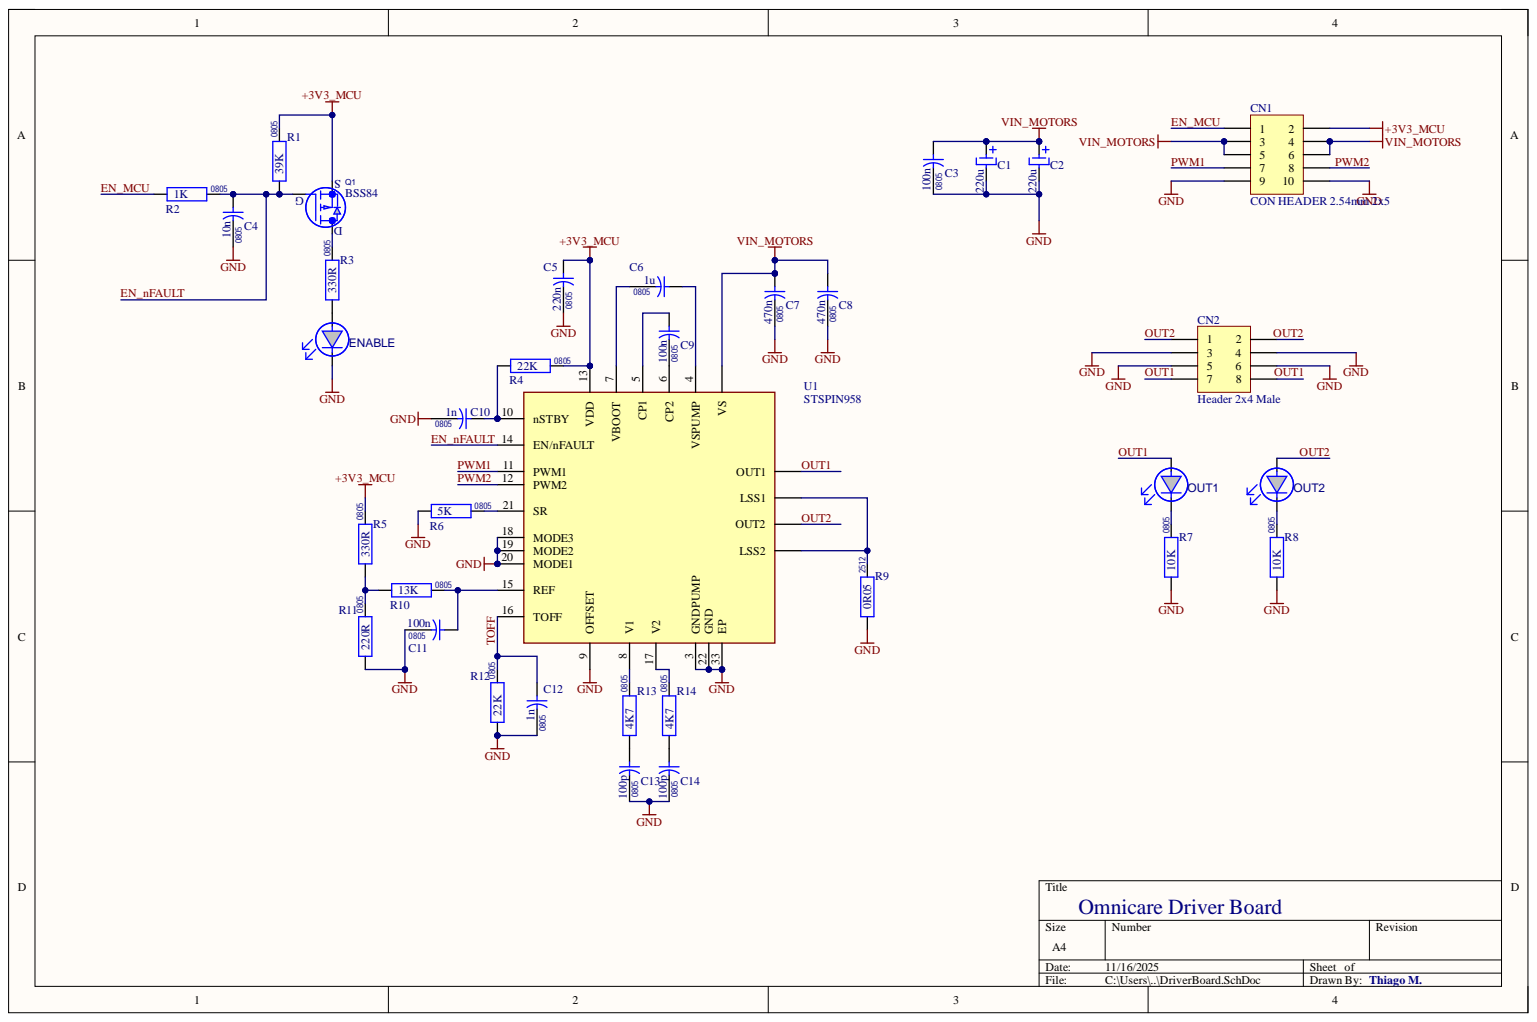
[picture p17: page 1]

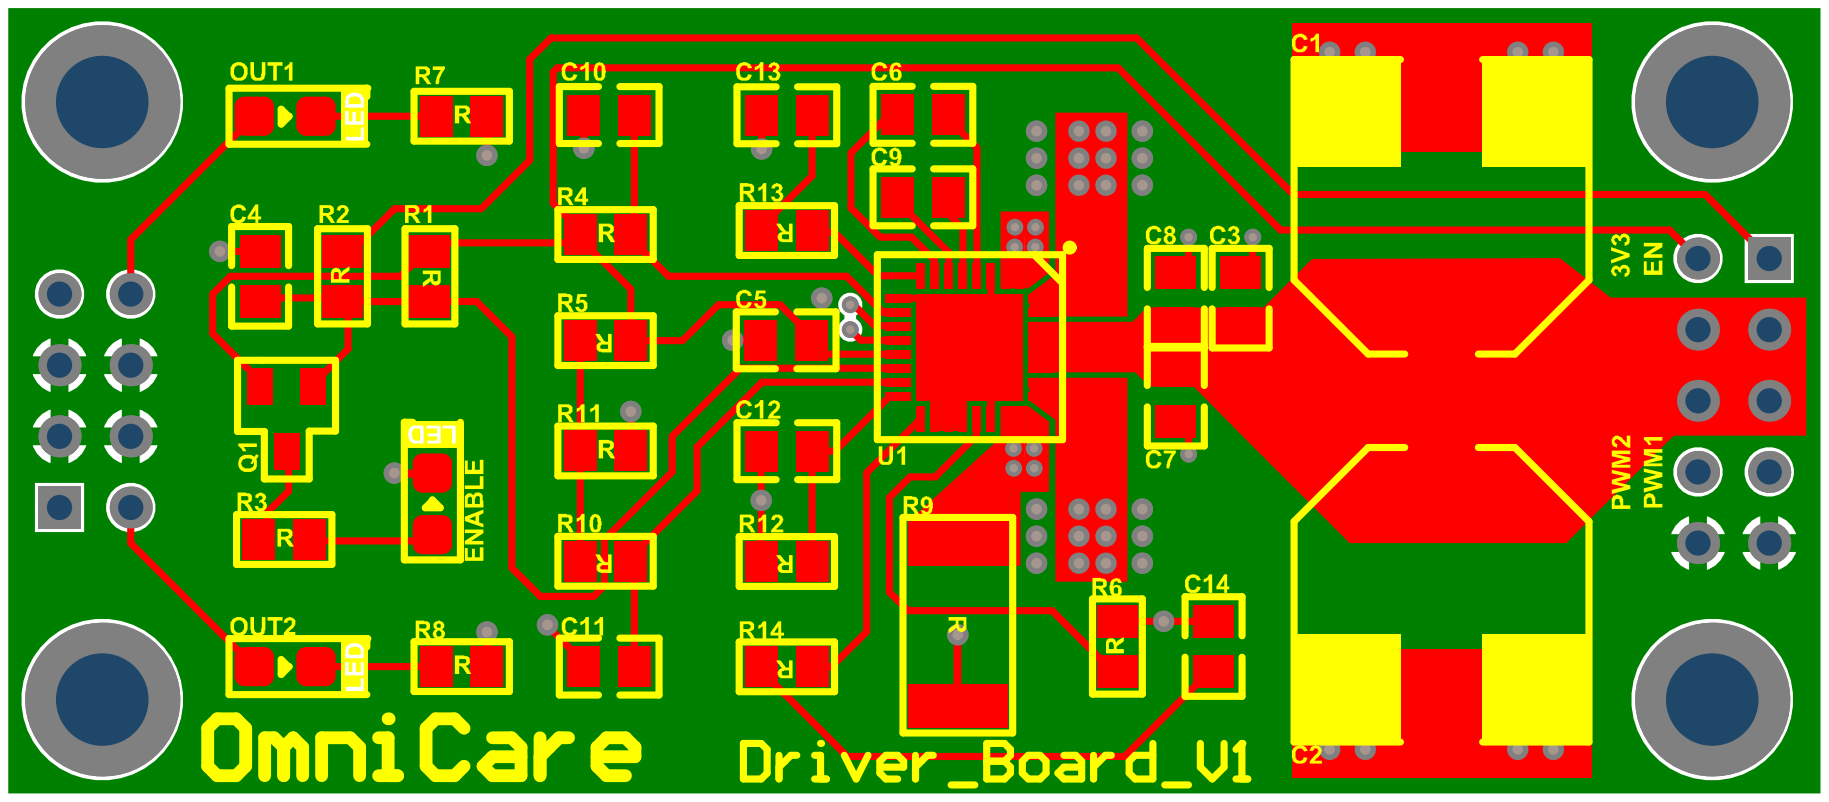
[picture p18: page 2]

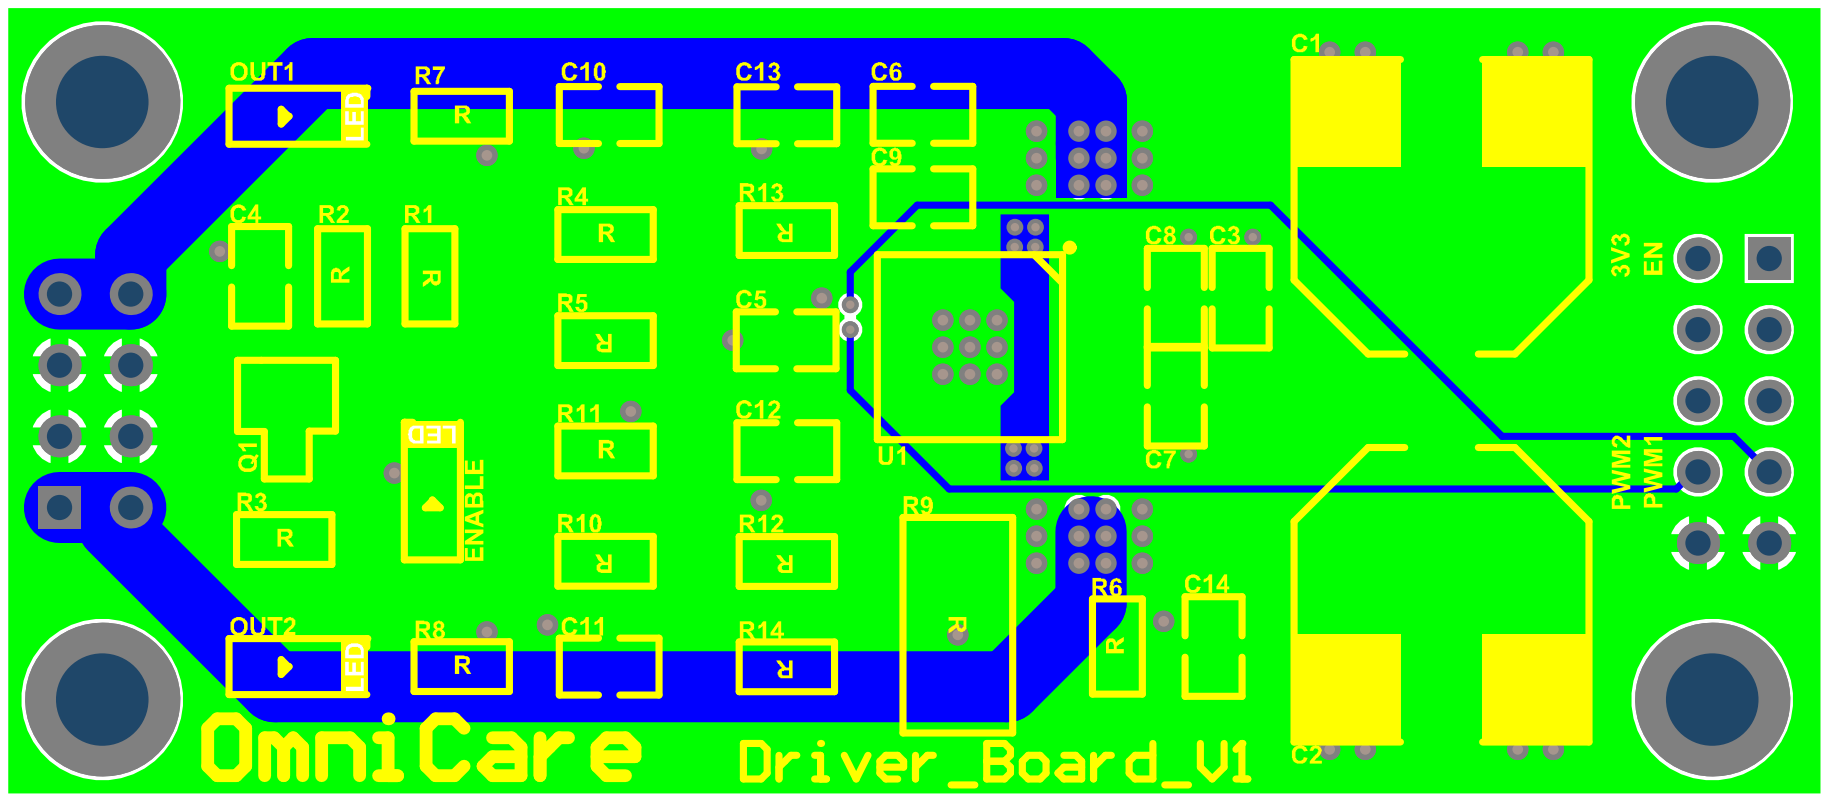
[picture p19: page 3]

Comment | Designator | Footprint | Quantity
220u | C1, C2 | CAPSMDELE 10x10.2mm | 2
100n | C3, C9, C11 | CAPSMDCER0805 | 3
10n | C4 | CAPSMDCER0805 | 1
220n | C5 | CAPSMDCER0805 | 1
1u | C6 | CAPSMDCER0805 | 1
470n | C7, C8 | CAPSMDCER0805 | 2
1n | C10, C12 | CAPSMDCER0805 | 2
100p | C13, C14 | CAPSMDCER0805 | 2
CON HEADER2.54mm 2x5 | CN1 | CON HEADER2.54mm 2x5 | 1
Header 2x4Male | CN2 | Header 2x4Male-Footprint-1 | 1
RED | ENABLE, OUT1, OUT2 | LEDSMD0805 | 3
BSS84 | Q1 | SOT23 | 1
39K | R1 | RESSMD0805 | 1
1K | R2 | RESSMD0805 | 1
330R | R3, R5 | RESSMD0805 | 2
22K | R4, R12 | RESSMD0805 | 2
5K | R6 | RESSMD0805 | 1
10K | R7, R8 | RESSMD0805 | 2
0R05 | R9 | RESSMD2512 | 1
13K | R10 | RESSMD0805 | 1
220R | R11 | RESSMD0805 | 1
4K7 | R13, R14 | RESSMD0805 | 2
STSPIN958 | U1 | NBG32(VFQFPN 32) | 1

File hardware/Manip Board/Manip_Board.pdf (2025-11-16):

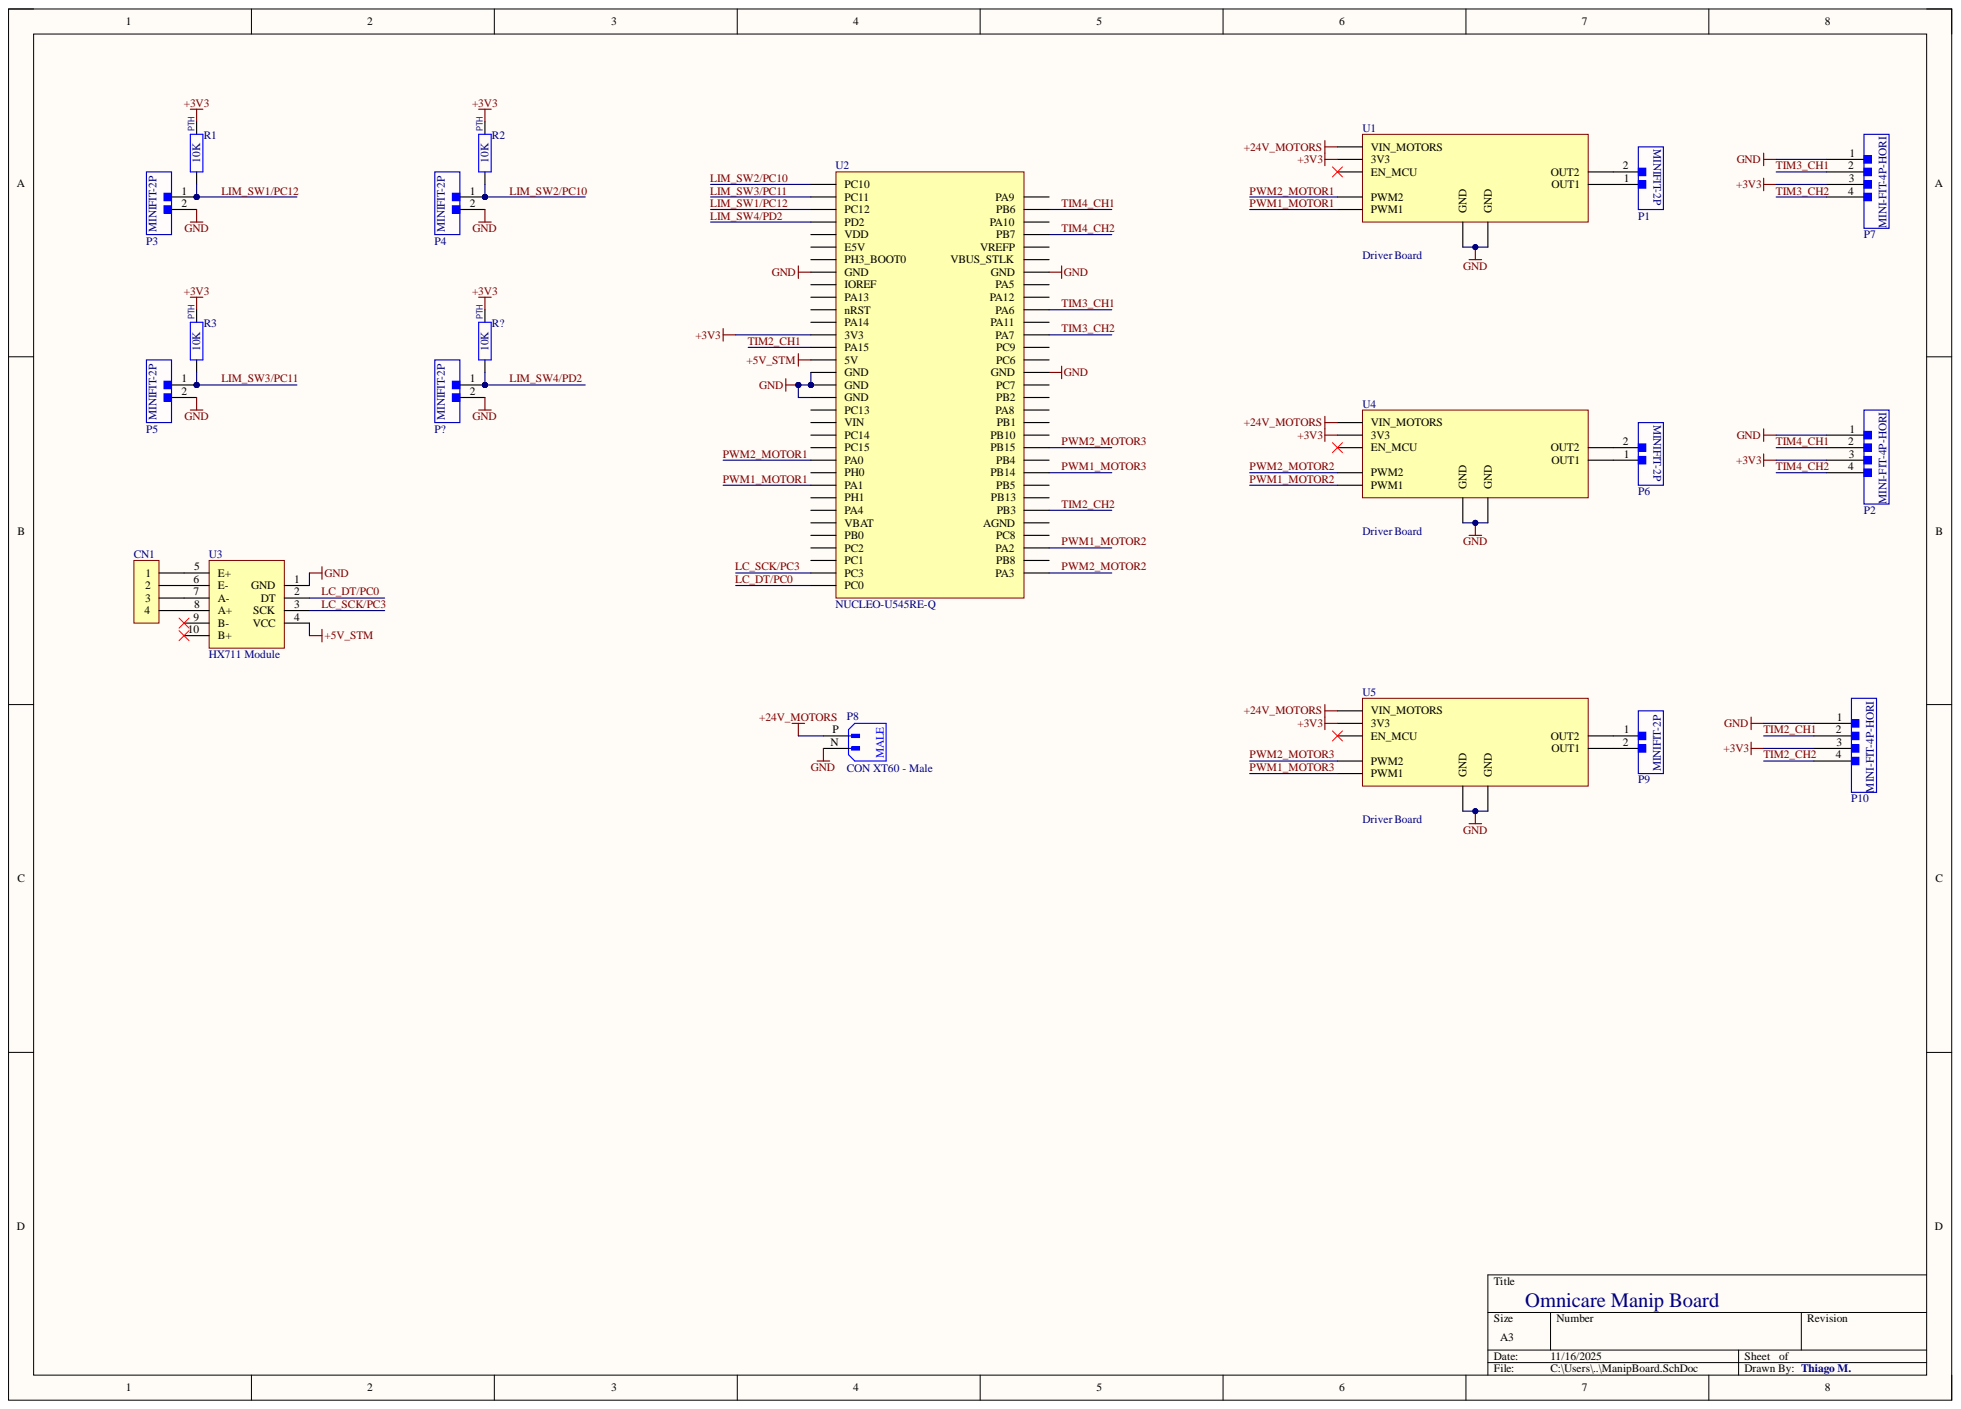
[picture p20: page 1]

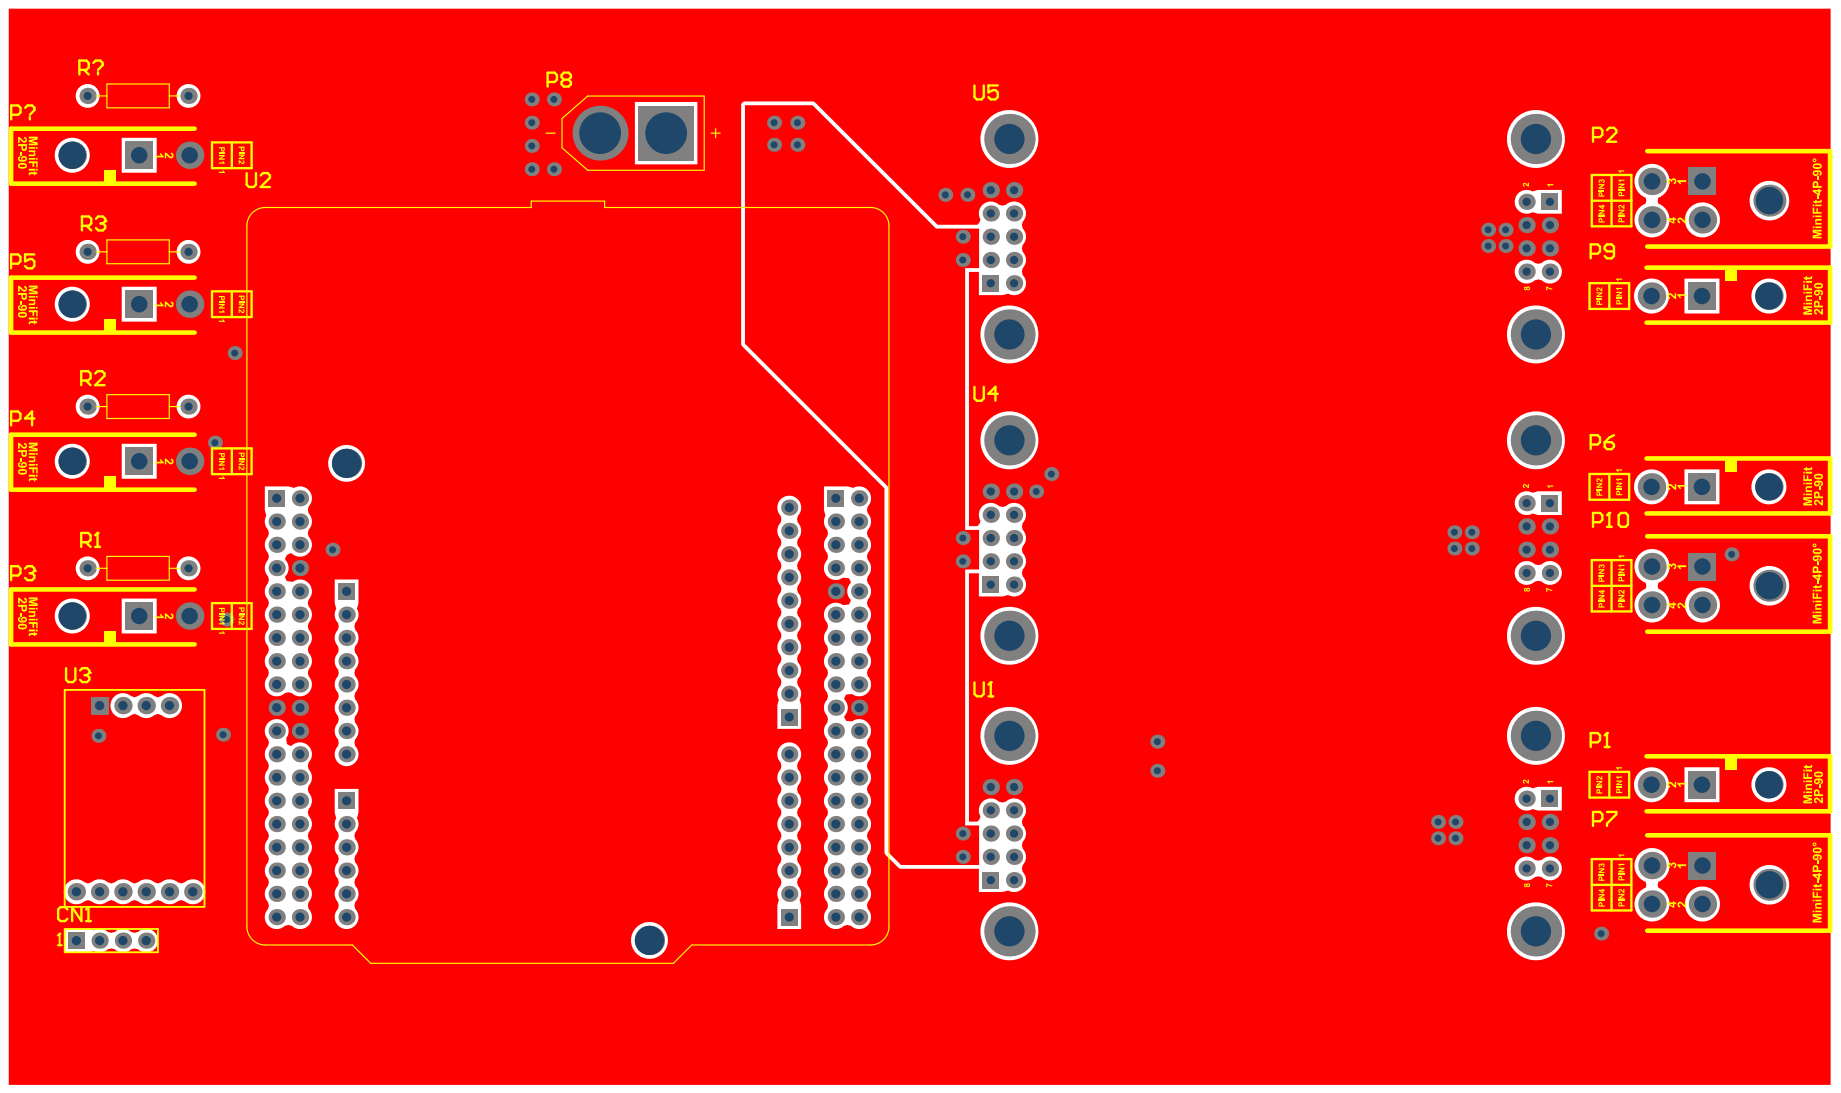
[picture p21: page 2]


Comment | Designator | Footprint | Quantity
CON HEADER2.54mm 1x4 | CN1 | CON HEADER2.54mm 1x4 | 1
CON MINI FIT2P- 1x2 | P1, P3, P4, P5, P6, P9, P? | CON MINI FIT2POS-1x2- 90DG | 7
CON MINI FIT4P- 2x2-HORIZONTAL | P2, P7, P10 | CON MINI FIT4POS-2x2- 90DG | 3
CON XT60- Male | P8 | CON XT60MALE | 1
10K | R1, R2, R3, R? | RESPTH | 4
Driver Board | U1, U4, U5 | Driver Board | 3
NUCLEO-U545RE-Q | U2 | NUCLEO64 | 1
HX711Module | U3 | HX711XFW | 1

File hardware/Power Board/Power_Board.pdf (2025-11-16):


Step Up and Down 24V

VERIFICAR SE MACHO OU FEMEA


Comment | Designator | Footprint | Quantity
STPS10H100CT | D1, D3 | TO-220AB | 2
1N4004 | D2 | DO41 | 1
Zener PTH- Gen. | D4 | DO41- Zener | 1
FuseHolder 20x5 | F1 | FUSEHOLDER20x5 | 1
XT60-M-180 | J1, J2, J3, J4 | AMASS_XT60-M | 4
LEDPTH- Gen. | LD1 | DO41 | 1
CON XT60- Male | P1, P2 | CON XT60MALE | 2
CON KF2EDGRC-5.08-02P | P3, P4, P5, P6 | BORNE5.08RA2P | 4
IRF9540N | Q1, Q2 | TO-220AB | 2
BC548 | Q3, Q4 | TO-92LPM | 2
10K | R1, R2, R6 | RESPTH | 3
20K | R3, R4, R5 | RESPTH | 3
50K | R7, R8 | RESPTH | 2

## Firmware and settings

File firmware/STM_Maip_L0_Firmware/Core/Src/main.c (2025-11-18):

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
/* Includes ------------------------------------------------------------------*/
#include "main.h"

/* USER CODE BEGIN Includes */

#include <string.h>
#include <stdbool.h>
#include <stdlib.h>
#include <stdio.h>

/* USER CODE END Includes */

/* USER CODE BEGIN PD */

#define RX_BUFFER_SIZE 64

/* USER CODE END PD */

TIM_HandleTypeDef htim2;
TIM_HandleTypeDef htim22;

UART_HandleTypeDef huart2;

/* USER CODE BEGIN PV */

bool limit_switch_state[4] = {false, false, false, false};
int16_t motorsPWM[3] = {0, 0, 0};

// UART buffers e flags
static uint8_t rx_byte;
static uint8_t rx_buffer[RX_BUFFER_SIZE];
static volatile uint8_t rx_index = 0;
static volatile bool message_ready = false;

/* USER CODE END PV */

void SystemClock_Config(void);
static void MX_GPIO_Init(void);
static void MX_TIM2_Init(void);
static void MX_TIM22_Init(void);
static void MX_USART2_UART_Init(void);
/* USER CODE BEGIN PFP */

void processCommand(const char *cmd);
void computeMotors();
void send_limit_switch_state(void);

/* USER CODE END PFP */

/* USER CODE BEGIN 0 */

void HAL_UART_RxCpltCallback(UART_HandleTypeDef *huart)
{
    if (huart->Instance == USART2)
    {
        if (rx_byte == '\n' || rx_byte == '\r')  // Detectou fim da mensagem
        {
            rx_buffer[rx_index] = '\0'; // Finaliza string
            rx_index = 0;               // Reinicia índice

            processCommand(rx_buffer);
        }
        else
        {
            // Adiciona ao buffer se couber
            if (rx_index < RX_BUFFER_SIZE - 1)
            {
                rx_buffer[rx_index++] = rx_byte;
            }
        }

        HAL_UART_Receive_IT(&huart2, &rx_byte, sizeof(rx_byte));
    }
}

void send_limit_switch_state(void)
{
    char msg[10];

    snprintf(msg, sizeof(msg),
             "%d %d %d %d\n",
             limit_switch_state[0],
             limit_switch_state[1],
             limit_switch_state[2],
             limit_switch_state[3]);

    HAL_UART_Transmit(&huart2, (uint8_t*)msg, strlen(msg), HAL_MAX_DELAY);
}


void processCommand(const char *cmd)
{
	HAL_GPIO_TogglePin(LD3_GPIO_Port, LD3_Pin);

	if(cmd[0] == 'm'){
		char *token = strtok(cmd, " ");
		char _ = token[0];
		for (int i = 0; i < 3; i++) {
		   token = strtok(NULL, " ");
		   motorsPWM[i] = (int16_t)atoi(token);
		}
	}
}

void computeMotors(){
	int pwm_positive = motorsPWM[0];
	int pwm_negative = 0;
	if(pwm_positive < 0)
	{
		pwm_positive = 0;
		pwm_negative = abs(motorsPWM[0]);
	}

	if(pwm_positive > 255) pwm_positive = 255;
	if(pwm_negative > 255) pwm_negative = 255;

	if(pwm_positive > 0 && limit_switch_state[0] == 1){
		pwm_positive = 0;
		motorsPWM[0] = 0;
	}
	if(pwm_negative > 0 && limit_switch_state[1] == 1){
		pwm_positive = 0;
		motorsPWM[0] = 0;
	}
	TIM2->CCR1 = pwm_negative;
	TIM2->CCR2 = pwm_positive;



	pwm_positive = motorsPWM[1];
	pwm_negative = 0;
	if(pwm_positive < 0)
	{
		pwm_positive = 0;
		pwm_negative = abs(motorsPWM[1]);
	}

	if(pwm_positive > 255) pwm_positive = 255;
	if(pwm_negative > 255) pwm_negative = 255;

	if(pwm_positive > 0 && limit_switch_state[3] == 1){
		pwm_positive = 0;
		motorsPWM[1] = 0;
	}
	if(pwm_negative > 0 && limit_switch_state[2] == 1){
		pwm_positive = 0;
		motorsPWM[1] = 0;
	}


	TIM22->CCR1 = pwm_positive;
	TIM22->CCR2 = pwm_negative;



	pwm_positive = motorsPWM[2];
	pwm_negative = 0;
	if(pwm_positive < 0)
	{
		pwm_positive = 0;
		pwm_negative = abs(motorsPWM[2]);
	}

	if(pwm_positive > 255) pwm_positive = 255;
	if(pwm_negative > 255) pwm_negative = 255;

	TIM2->CCR3 = pwm_positive;
	TIM2->CCR4 = pwm_negative;
}

/* USER CODE END 0 */

/**
  * @brief  The application entry point.
  * @retval int
  */
int main(void)
{

  /* MCU Configuration--------------------------------------------------------*/

  /* Reset of all peripherals, Initializes the Flash interface and the Systick. */
  HAL_Init();

  /* Configure the system clock */
  SystemClock_Config();

  /* Initialize all configured peripherals */
  MX_GPIO_Init();
  MX_TIM2_Init();
  MX_TIM22_Init();
  MX_USART2_UART_Init();
  /* USER CODE BEGIN 2 */

  HAL_UART_Receive_IT(&huart2, &rx_byte, sizeof(rx_byte));

  /* USER CODE END 2 */

  /* Infinite loop */
  /* USER CODE BEGIN WHILE */
  uint64_t time_last_msg_send = HAL_GetTick();
  while (1)
  {
    /* USER CODE END WHILE */

    /* USER CODE BEGIN 3 */
	computeMotors();
	if(HAL_GetTick() - time_last_msg_send > 500){
		send_limit_switch_state();
	}
  }
  /* USER CODE END 3 */
}

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
/* USER CODE BEGIN 4 */

void HAL_GPIO_EXTI_Callback(uint16_t GPIO_Pin)
{
    switch (GPIO_Pin)
    {
        case GPIO_PIN_4:
            limit_switch_state[0] = (HAL_GPIO_ReadPin(GPIOB, GPIO_PIN_4) == GPIO_PIN_RESET);
            break;

        case GPIO_PIN_5:
            limit_switch_state[1] = (HAL_GPIO_ReadPin(GPIOB, GPIO_PIN_5) == GPIO_PIN_RESET);
            break;

        case GPIO_PIN_8:
            limit_switch_state[2] = (HAL_GPIO_ReadPin(GPIOA, GPIO_PIN_8) == GPIO_PIN_RESET);
            break;

        case GPIO_PIN_11:
            limit_switch_state[3] = (HAL_GPIO_ReadPin(GPIOA, GPIO_PIN_11) == GPIO_PIN_RESET);
            break;
    }
}

/* USER CODE END 4 */
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


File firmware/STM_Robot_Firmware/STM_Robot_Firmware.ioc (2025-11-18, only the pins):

Mcu.UserName=STM32U545RETxQ
PA0.Signal=S_TIM5_CH1
PA1.Signal=S_TIM5_CH2
PA10.Signal=USART1_RX
PA11.Signal=USB_DM
PA12.Signal=USB_DP
PA2.Signal=S_TIM5_CH3
PA3.Signal=S_TIM5_CH4
PA6.Signal=S_TIM3_CH1
PA7.Signal=S_TIM3_CH2
PA9.Signal=USART1_TX
PB14.Signal=S_TIM15_CH1
PB15.Signal=S_TIM15_CH2
PB6.Signal=S_TIM4_CH1
PB7.Signal=S_TIM4_CH2

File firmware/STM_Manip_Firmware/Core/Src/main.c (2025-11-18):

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
/* Includes ------------------------------------------------------------------*/
#include "app_threadx.h"
#include "main.h"

/* USER CODE BEGIN Includes */

#include "pin_mapping.h"
#include "robot_data.h"
#include "stdio.h"


/* USER CODE END Includes */


TIM_HandleTypeDef htim2;
TIM_HandleTypeDef htim3;
TIM_HandleTypeDef htim4;
TIM_HandleTypeDef htim5;
TIM_HandleTypeDef htim15;

UART_HandleTypeDef huart1;

PCD_HandleTypeDef hpcd_USB_DRD_FS;

/* USER CODE BEGIN PV */

MotorData motors_data[3];

/* USER CODE END PV */

void SystemClock_Config(void);
static void SystemPower_Config(void);
static void MX_GPIO_Init(void);
static void MX_ICACHE_Init(void);
static void MX_TIM2_Init(void);
static void MX_TIM3_Init(void);
static void MX_TIM4_Init(void);
static void MX_TIM5_Init(void);
static void MX_TIM15_Init(void);
static void MX_USART1_UART_Init(void);
/* USER CODE BEGIN 0 */

void HAL_TIM_IC_CaptureCallback(TIM_HandleTypeDef *htim)
{
	if(htim == ENCODER_0)
	{
		motors_data[0].encoder_actual_count = __HAL_TIM_GET_COUNTER(htim)/4;
		if(ENCODERS_DIRECTION[0] == -1)
		{
			motors_data[0].encoder_actual_count = 0xFFFFFFFF/4 - motors_data[0].encoder_actual_count;
		}
	}
	else if (htim == ENCODER_1)
	{
		motors_data[1].encoder_actual_count = __HAL_TIM_GET_COUNTER(htim)/4;
		if(ENCODERS_DIRECTION[1] == -1)
		{
			motors_data[1].encoder_actual_count = 0xFFFFFFFF/4 - __HAL_TIM_GET_COUNTER(htim)/4;
		}
		else motors_data[1].encoder_actual_count = __HAL_TIM_GET_COUNTER(htim)/4;
	}
	else
	{
		motors_data[2].encoder_actual_count = __HAL_TIM_GET_COUNTER(htim)/4;
		if(ENCODERS_DIRECTION[2] == -1)
		{
			motors_data[2].encoder_actual_count = 0xFFFFFFFF/4 - motors_data[2].encoder_actual_count;
		}

	}
}

/* USER CODE END 0 */

/**
  * @brief  The application entry point.
  * @retval int
  */
int main(void)
{

  /* MCU Configuration--------------------------------------------------------*/

  /* Reset of all peripherals, Initializes the Flash interface and the Systick. */
  HAL_Init();

  /* Configure the System Power */
  SystemPower_Config();

  /* Configure the system clock */
  SystemClock_Config();

  /* Initialize all configured peripherals */
  MX_GPIO_Init();
  MX_ICACHE_Init();
  MX_TIM2_Init();
  MX_TIM3_Init();
  MX_TIM4_Init();
  MX_TIM5_Init();
  MX_TIM15_Init();
  MX_USART1_UART_Init();
  /* USER CODE BEGIN 2 */

	HAL_TIM_Encoder_Start_IT(ENCODER_0, TIM_CHANNEL_ALL);
	HAL_TIM_Encoder_Start_IT(ENCODER_1, TIM_CHANNEL_ALL);
	HAL_TIM_Encoder_Start_IT(ENCODER_2, TIM_CHANNEL_ALL);

  HAL_TIM_PWM_Start(&htim5, TIM_CHANNEL_1);
  HAL_TIM_PWM_Start(&htim5, TIM_CHANNEL_2);
  HAL_TIM_PWM_Start(&htim5, TIM_CHANNEL_3);
  HAL_TIM_PWM_Start(&htim5, TIM_CHANNEL_4);
  HAL_TIM_PWM_Start(&htim15, TIM_CHANNEL_1);
  HAL_TIM_PWM_Start(&htim15, TIM_CHANNEL_2);

//  int test = 1;
//  printf((char* )test);
//  HAL_UART_Transmit(&huart1,(uint8_t *)"\r", sizeof("\r"), 1000);
  /* USER CODE END 2 */

  MX_ThreadX_Init();

  /* We should never get here as control is now taken by the scheduler */

  /* Infinite loop */
  /* USER CODE BEGIN WHILE */
  while (1)
  {
    /* USER CODE END WHILE */

    /* USER CODE BEGIN 3 */
  }
  /* USER CODE END 3 */
}

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
/* USER CODE BEGIN 4 */
/**
  * @brief  Retargets the C library printf function to the USART.
  *   None
  * @retval None
  */
PUTCHAR_PROTOTYPE
{
  /* Place your implementation of fputc here */
  /* e.g. write a character to the USART1 and Loop until the end of transmission */
  HAL_UART_Transmit(&huart1, (uint8_t *)&ch, 1, 0xFFFF);
//  HAL_UART_Transmit(&huart1, (uint8_t *)"\r", 2, 0xFFFF);

  return ch;
}


void HAL_GPIO_EXTI_Rising_Callback(uint16_t GPIO_Pin){
	switch(GPIO_Pin){
		case GPIO_PIN_2:
			limit_switch_state[0] = 0;
			break;
		case GPIO_PIN_10:
			limit_switch_state[1] = 0;
			break;
		case GPIO_PIN_11:
			limit_switch_state[2] = 0;
			break;
		case GPIO_PIN_12:
			limit_switch_state[3] = 0;
			break;
	}
}

void HAL_GPIO_EXTI_Falling_Callback(uint16_t GPIO_Pin){
	switch(GPIO_Pin){
		case GPIO_PIN_2:
			limit_switch_state[0] = 1;
			break;
		case GPIO_PIN_10:
			limit_switch_state[1] = 1;
			break;
		case GPIO_PIN_11:
			limit_switch_state[2] = 1;
			break;
		case GPIO_PIN_12:
			limit_switch_state[3] = 1;
			break;
	}
}


/* USER CODE END 4 */

/**
  * @brief  Period elapsed callback in non blocking mode
  * @note   This function is called  when TIM6 interrupt took place, inside
  * HAL_TIM_IRQHandler(). It makes a direct call to HAL_IncTick() to increment
  * a global variable "uwTick" used as application time base.
  * @param  htim : TIM handle
  * @retval None
  */
void HAL_TIM_PeriodElapsedCallback(TIM_HandleTypeDef *htim)
{
  if (htim->Instance == TIM6) {
    HAL_IncTick();
  }
}

/**
  * @brief  This function is executed in case of error occurrence.
  * @retval None
  */
void Error_Handler(void)
{
  /* USER CODE BEGIN Error_Handler_Debug */
  /* User can add his own implementation to report the HAL error return state */
  __disable_irq();
  while (1)
  {
  }
  /* USER CODE END Error_Handler_Debug */
}

#ifdef  USE_FULL_ASSERT
/**
  * @brief  Reports the name of the source file and the source line number
  *         where the assert_param error has occurred.
  * @param  file: pointer to the source file name
  * @param  line: assert_param error line source number
  * @retval None
  */
void assert_failed(uint8_t *file, uint32_t line)
{
  /* USER CODE BEGIN 6 */
  /* User can add his own implementation to report the file name and line number,
     ex: printf("Wrong parameters value: file %s on line %d\r\n", file, line) */
  /* USER CODE END 6 */
}
#endif /* USE_FULL_ASSERT */

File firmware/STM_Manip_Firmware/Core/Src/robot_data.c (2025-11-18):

#include "robot_data.h"

#include <math.h>
#include <stdlib.h>
#include <stdio.h>
#include <string.h>

#include "tx_api.h"
#include "pin_mapping.h"
#include "stm32u5xx_hal.h"

extern MotorData motors_data[3];

#define INTEGRAL_MAX 1000  // Valor máximo da integral
#define INTEGRAL_MIN -1000 // Valor mínimo da integral

void Init_Motors_Data()
{
	init_encoders();
	motors_data[1].set_point_velocity = 0;
	motors_data[2].set_point_velocity = 0;

	for(int i=0; i<3; i++){
		motors_data[i].set_point_velocity = 0;
		motors_data[i].atual_velocity = 0;

		motors_data[i].error = 0;
		motors_data[i].dt = 0;
		motors_data[i].PWM = 0;


		motors_data[i].PID[0] = 0.01;
		motors_data[i].PID[1] = 0.0005;
		motors_data[i].PID[2] = 0;
	}

	init_limit_switches();
}

void actual_velocity(int Motor_Number,uint32_t dt)
{
	int32_t diff_count = motors_data[Motor_Number].encoder_actual_count - motors_data[Motor_Number].encoder_last_count;

	// verificacao para tratar estouro do buffer
 	if(abs(diff_count) > 2e16)
	{
		diff_count = (2e32 - abs(diff_count)) * (-diff_count/(abs(diff_count)));
	}

 	// pulse/second = (pulse/(ms * 10 ^-3))
 	int32_t encoder_per_second = (int32_t) (diff_count/(dt*1e-3));

 	motors_data[Motor_Number].atual_velocity = encoder_per_second;

	// Salvando o valor do count para proxima atualizacao de dados
 	motors_data[Motor_Number].encoder_last_count = motors_data[Motor_Number].encoder_actual_count;


}

void update_all_motors_data(uint32_t dt)
{
	actual_velocity(0,dt);
	actual_velocity(1,dt);
	actual_velocity(2,dt);
}



void set_motors_velocity_string(char *char_velocity_list)
{
	int32_t count_per_seconds_motors[3];
	char *token = strtok(char_velocity_list, " ");
	char _ = token[0];

	// Pegamos os próximos números
	for (int i = 0; i < 3; i++) {
	   token = strtok(NULL, " ");
	   count_per_seconds_motors[i] = (int32_t)atoi(token);
	}

	set_motors_velocity(count_per_seconds_motors);
}


void set_pid_config(char *char_pid_list)
{
	float pid[3];
	char *token = strtok(char_pid_list, " ");
	char _ = token[0];

	// Pegamos os próximos números
	for (int i = 0; i < 3; i++) {
	   token = strtok(NULL, " ");
	   pid[i] = atof(token);
	}

	for(int i=0; i<3; i++)
	{
		motors_data[i].PID[0] = pid[0];
		motors_data[i].PID[1] = pid[1];
		motors_data[i].PID[2] = pid[2];
	}
}

void set_motors_velocity(int32_t *velocity_list)
{
	/*
	 * Se estiver no limite inferior e tentar subir ou
	 * no limite superior e tentar descer define a velocidade
	 * como 0
	 */
	if((limit_switch_state[0] == 1 && velocity_list[0] < 0) ||
	   ((limit_switch_state[1] == 1 && velocity_list[0] > 0))){
		motors_data[0].set_point_velocity = 0;
	} else {
		motors_data[0].set_point_velocity = velocity_list[0];
	}

	if((limit_switch_state[2] == 1 && velocity_list[1] < 0) ||
	  ((limit_switch_state[3] == 1 && velocity_list[1] > 0))){
		motors_data[1].set_point_velocity = 0;
	} else {
		motors_data[1].set_point_velocity = velocity_list[1];
	}

	motors_data[2].set_point_velocity = velocity_list[2];

}

void update_velocity(int *velocitys_pwm){


	int pwm_positive = velocitys_pwm[0];
	int pwm_negative = 0;
	if(pwm_positive < 0)
	{
		pwm_positive = 0;
		pwm_negative = abs(velocitys_pwm[0]);
	}

	if(pwm_positive > 255) pwm_positive = 255;
	if(pwm_negative > 255) pwm_negative = 255;

	MOTOR0_PMW_POSITIVE = pwm_positive;
	MOTOR0_PMW_NEGATIVE = pwm_negative;



	pwm_positive = velocitys_pwm[1];
	pwm_negative = 0;
	if(pwm_positive < 0)
	{
		pwm_positive = 0;
		pwm_negative = abs(velocitys_pwm[1]);
	}

	if(pwm_positive > 255) pwm_positive = 255;
	if(pwm_negative > 255) pwm_negative = 255;

	MOTOR1_PMW_POSITIVE = pwm_positive;
	MOTOR1_PMW_NEGATIVE = pwm_negative;



	pwm_positive = velocitys_pwm[2];
	pwm_negative = 0;
	if(pwm_positive < 0)
	{
		pwm_positive = 0;
		pwm_negative = abs(velocitys_pwm[2]);
	}

	if(pwm_positive > 255) pwm_positive = 255;
	if(pwm_negative > 255) pwm_negative = 255;

	MOTOR2_PMW_POSITIVE = pwm_positive;
	MOTOR2_PMW_NEGATIVE = pwm_negative;

}

void motor_pid_control_thread_entry(unsigned long thread_input)
{
	int32_t last_error[3] = {0, 0 ,0};
	int32_t error[3] = {0, 0 ,0};
	int32_t integral[3] = {0, 0 ,0};
	float derivate[3] = {0, 0 ,0};
	unsigned long atual_ms = (tx_time_get() * 1000) / TX_TIMER_TICKS_PER_SECOND;
	uint32_t last_time_ms = atual_ms;
	int first_time = 1;
	int motor_vel_pwm[3] = {0};


	while(1){
		if((limit_switch_state[0] == 1 && motors_data[0].set_point_velocity < 0) ||
		   ((limit_switch_state[1] == 1 && motors_data[0].set_point_velocity > 0))){
			motors_data[0].set_point_velocity = 0;
		}

		if((limit_switch_state[2] == 1 && motors_data[1].set_point_velocity < 0) ||
		   ((limit_switch_state[3] == 1 && motors_data[1].set_point_velocity > 0))){
			motors_data[1].set_point_velocity = 0;
		}

		if(first_time){
			first_time = 0;
		}
		else{
			atual_ms = (tx_time_get() * 1000) / TX_TIMER_TICKS_PER_SECOND;
			uint32_t dt = atual_ms - last_time_ms;


			// update all motors
			update_all_motors_data(dt);


			for(int i=0; i<3; i++){
				error[i] 		= motors_data[i].set_point_velocity - motors_data[i].atual_velocity;
				motors_data[i].error = error[i];

//				atual_ms = (tx_time_get() * 1000) / TX_TIMER_TICKS_PER_SECOND;
//				dt 				= atual_ms - last_time_ms;
				motors_data[i].dt = dt;

				integral[i] 	+= error[i]*dt;

				// Evitar windup da integral
				if (integral[i] > INTEGRAL_MAX) integral[i] = INTEGRAL_MAX;
				if (integral[i] < INTEGRAL_MIN) integral[i] = INTEGRAL_MIN;


//				derivate[i] 	= (error[i] - last_error[i])/dt;

				last_error[i] = error[i];
				motor_vel_pwm[i] += motors_data[i].PID[0] * error[i] +  motors_data[i].PID[1] * integral[i] + motors_data[i].PID[2] * derivate[i];
				motors_data[i].PWM = motor_vel_pwm[i];

				if(abs(motor_vel_pwm[i]) >= 100000)
				{
					motor_vel_pwm[i] = abs(motor_vel_pwm[i])/motor_vel_pwm[i] * -15;
				}
			}
			update_velocity(motor_vel_pwm);
		}
//		atual_ms = (tx_time_get() * 1000) / TX_TIMER_TICKS_PER_SECOND;
		last_time_ms = atual_ms;
		tx_thread_sleep(1);
	}
}



const int ENCODERS_DIRECTION[] = {1, 1, 1};

void init_encoders()
{
	motors_data[0].encoder_actual_count= 0;
	motors_data[1].encoder_actual_count = 0;
	motors_data[2].encoder_actual_count = 0;

	motors_data[0].encoder_last_count= 0;
	motors_data[1].encoder_last_count = 0;
	motors_data[2].encoder_last_count = 0;

}

uint8_t limit_switch_state [4];
void init_limit_switches(){

	limit_switch_state[0] = (HAL_GPIO_ReadPin(GPIOC, GPIO_PIN_10) == 0) ? 1 : 0;
	limit_switch_state[1] = (HAL_GPIO_ReadPin(GPIOC, GPIO_PIN_11) == 0) ? 1 : 0;
	limit_switch_state[2] = (HAL_GPIO_ReadPin(GPIOC, GPIO_PIN_12) == 0) ? 1 : 0;
	limit_switch_state[3] = (HAL_GPIO_ReadPin(GPIOD, GPIO_PIN_2) == 0) ? 1 : 0;

}

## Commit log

2025-06-14 Update: Changing LiDAR (C1 -> S1) in bringup launch
2025-06-14 Update: Omnidirecional Subomodule -> the max speed with 24V
2025-06-17 Update: Increase the X and Y of Box Filter of LiDAR
2025-06-19 Add camera to xacro && Add camera to gazebo && Update omnicare vision to multiple pkgs format
    [camera.xacro, robot.xacro]
2025-07-07 Add yolo weights for jetson
2025-07-07 Add floor detector launch to detect wich device is runing && Update floor detector node to run in jetson and remove imshow
2025-07-08 ADD: Switch floor service is working on Gazebo ( Need to validate on real robot )
2025-07-08 Add: Custom service msg for SwitchFloor service
2025-07-08 Fix: Possible fix to solve the simulation LiDAR URDF bug
    [robot.xacro]
2025-07-09 Fix: Fixed the switchFloorService (service is working pretty well, need to validate on Real Robot
2025-07-09 Update: Just changing the service name to /omnicare/navigation/switch_floor
2025-07-13 Multiple changes applied to the floor detector node Improved floor detector reliability Add config file and more parameters to config Fix minor bugs
    [get_parameters.py]
2025-07-13 Update: Changes the checkpointService and switchFloorService to attend the omnicare_behavior_manager
2025-07-14 Update: Fix the enterInElevator action - the error was caused by rclpy spin_once inside of the action cb. Solution: Make a multi thread so you can get the update of LiDAR msgs on action loop
2025-07-15 Update: Finite State Machine almost done in simulation (need to validate in real robot) - States:
    - Floor Navigation (OK - Need to write a flag to know if the robot is going to the elevator or exiting from them)
    - ENTER_ELEVATOR (OK in simulation - on real robot, need to invert the front laser logics)
    - WAIT_FOR_FLOOR (NO - Tomorrow will see with Thiago
    - EXIT_ELEVATOR (OK - Need to see if we will use NAV2 or Custom Behavior - Need to tryout)
2025-07-15 Update: Add a new parameter on enterElevatorAction because on real robot the LiDAR is inverted
2025-07-16 Update: Adapting the Action for real robot (LiDAR and motors are diferente)
2025-07-17 Add: The map with good elevator (first one). I converted to use in Gazebo
    [goodElevatorImproved.stl]
2025-07-17 Update: Resize the walls of the Gazebo world
    [model.sdf]
2025-07-17 Update: elevator Action now get the median of the lasers
2025-07-17 Update: Fixed OmniCare sliding in Gazebo
    [robot.xacro]
2025-07-18 Add: Working on real2sim (Real Map -> Gazebo Map)
    [quartoAndarGoodElevatorImproved.stl]
2025-07-20 Update: Changing the STL Maps to another folder for organizing purpouse
    [goodElevatorImproved.stl, quartoAndarGoodElevatorImproved.stl]
2025-07-23 Update: Update the map with two floors (4th && 5th)
    [quartoAndarElevatorImproved.stl, quartoAndarGoodElevatorImproved.stl, quintoAndarElevatorImproved.stl]
2025-07-28 Add: Fix the map on Gazebo using Blender (Need to update the world on gazebo now!)
    [startingMapOnBlender.stl]
2025-07-30 Add: Big changes on maps (add maps for simulation && change some name of maps && update Gazebo world )
    [classicMap.stl, mapUsingConversion.stl, quartoAndar.stl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]
2025-08-06 Add dataset generator config file && Update dataset config file to save image to a dir with fixed fps
    [get_parameters.py]
2025-08-06 Add: Data now can be configured on the .yaml on omnicare_behavior for switch map (path of the map && robot initial coordinates)
2025-09-20 Update: fix behavior_manager && add tf_poses on navigation2 launch
    Fix: When switching to another floor, the list of checkpoints does not reset, so Nav2 ends up receiving checkpoints from both floors.
2025-10-04 Update: behavior_manager.py - add regex to filter display detection - add action new params so you can pass initial floor, target floor and simulation - add display cb
2025-10-05 Add: add converted 2D map into Gazebo (HU-USP)
    [HU_primeiroAndar.stl, HU_terceiroAndarHU.stl]
2025-10-06 WIP Update: new base pcb firmware pin mapping
2025-10-06 Update base firmware using definitive base pcb
2025-10-18 Update manip IOC to use limit switch
2025-10-19 Fix manip board pdf
2025-10-19 Add limit switch state limit
2025-11-08 ADD driver tester board firmware
2025-11-08 ADD Manip firmware with limit switch and set motor pwm
2025-11-15 Add: software RTC for jetson
2025-11-15 Fix: expression opens now on the display, not in the terminal
    [expressionsNode.py]
2025-11-16 Add PCB docs and Fabrications
2025-11-24 Move: moving ihr firmware to correct directory
    [firmware_hri.ino]
2025-12-03 Update: fix device on ros2 control description
    [ros2_control.xacro]
2025-12-03 Update: fix manip interface
    [serial_interface.py]
2025-12-22 Update: Go Horse feito no Behavior Manager para a apresentação de TCC 2

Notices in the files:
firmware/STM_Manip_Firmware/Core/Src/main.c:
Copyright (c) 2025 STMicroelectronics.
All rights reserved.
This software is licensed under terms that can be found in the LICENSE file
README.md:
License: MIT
